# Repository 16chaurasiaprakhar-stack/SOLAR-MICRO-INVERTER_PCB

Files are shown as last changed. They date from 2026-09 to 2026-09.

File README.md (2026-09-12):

# HAR-SMI-500 — High-Altitude Resilient 500W Solar Micro-Inverter

A high-altitude, extreme-environment **500W solar micro-inverter architecture** designed for operation under subzero temperatures and reduced atmospheric pressure. The design combines a **GaN-based LLC DC-DC conversion stage**, isolated planar transformer, **SiC full-bridge grid inverter**, LCL filtering, deterministic C2000 control, and ESP32-S3-based edge telemetry.

The system is designed around a **28–50V DC PV input**, **400V DC-link**, and **230V AC / 50Hz grid output**, with a target peak efficiency of **97.2%**.

HAR_SMI_500

## Key Features

* **500W continuous power conversion**
* 28–50V DC photovoltaic input
* 400V regulated DC-link
* 230V AC, 50Hz single-phase output
* GaN full-bridge LLC converter
* 2:20 planar isolation transformer
* SiC full-bridge grid inverter
* LCL output filter
* TI **TMS320F28379D C2000** real-time power controller
* **ESP32-S3** edge-processing and telemetry controller
* Galvanically isolated SPI communication using **ISO7741-Q1**
* Incremental Conductance MPPT
* SOGI-PLL grid synchronization
* 20kHz proportional-resonant current control
* Hardware over-voltage and over-current trip protection
* PT100, BME280, SHT45 and solar-irradiance sensing
* SX1262-based LoRaWAN telemetry
* Autonomous cold-start pre-heating using a 25W PTC heater
* High-altitude PCB clearance and creepage design
* Designed for −40°C to +55°C operation

The complete architecture is divided into hierarchical functional blocks covering PV input protection, LLC conversion, isolation and rectification, DC-link storage, SiC inversion, LCL filtering, gate drivers, sensing, dual-MCU control, RF telemetry, auxiliary power, and mechanical interfaces.

## Control & Protection

The C2000 controller provides the deterministic power-conversion control loop, including MPPT, LLC frequency modulation, grid synchronization, PR current control, and hardware Trip-Zone protection. The ESP32-S3 is isolated from the power-control domain and handles environmental diagnostics, cold-start supervision, data logging, and wireless telemetry.

## High-Altitude Design

The architecture incorporates altitude-aware electrical insulation design with an enforced **≥4.5 mm clearance** and **≥6.0 mm creepage**, along with milled isolation slots, conformal coating, selective potting, and minimized high-dv/dt power loops.

## Cold-Start System  
  

At temperatures below −20°C, the system enters an autonomous pre-heating state before enabling normal inverter operation. A 25W PTC heater combined with controlled GaN switching provides approximately 38W of heating power, targeting a transition from −40°C to −10°C in approximately 11.58 minutes.  



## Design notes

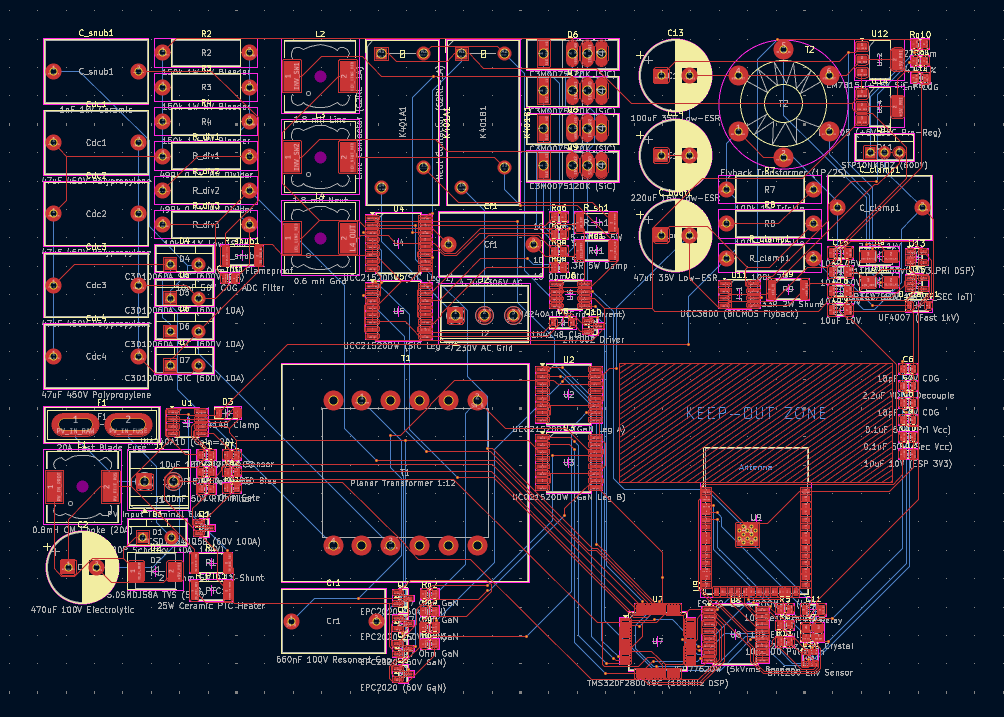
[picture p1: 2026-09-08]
PCB/looks and views/ROUTED.png

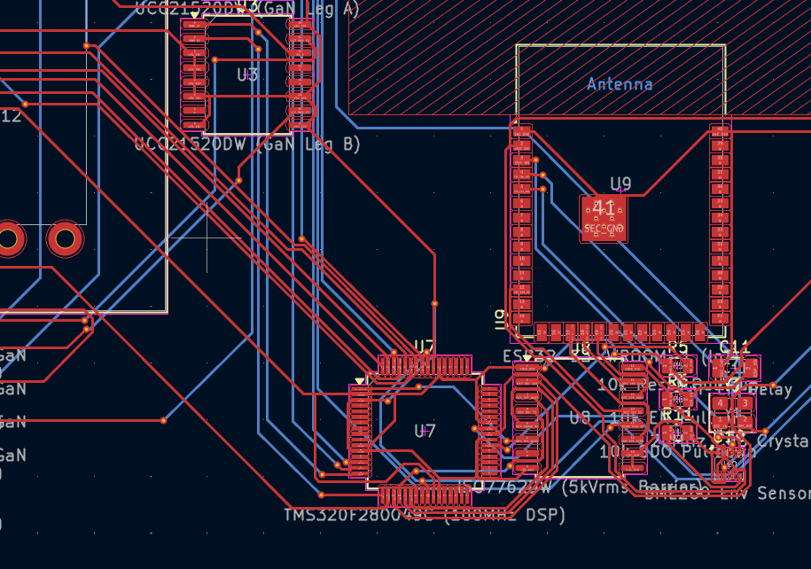
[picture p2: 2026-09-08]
PCB/looks and views/Screenshot 2026-09-08 202842.png

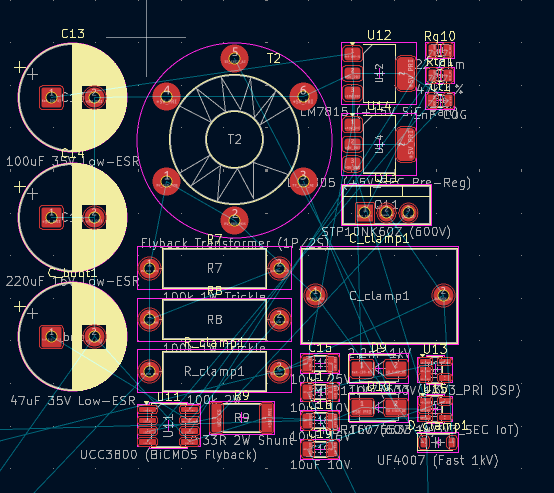
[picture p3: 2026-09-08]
PCB/looks and views/PCB.1.png

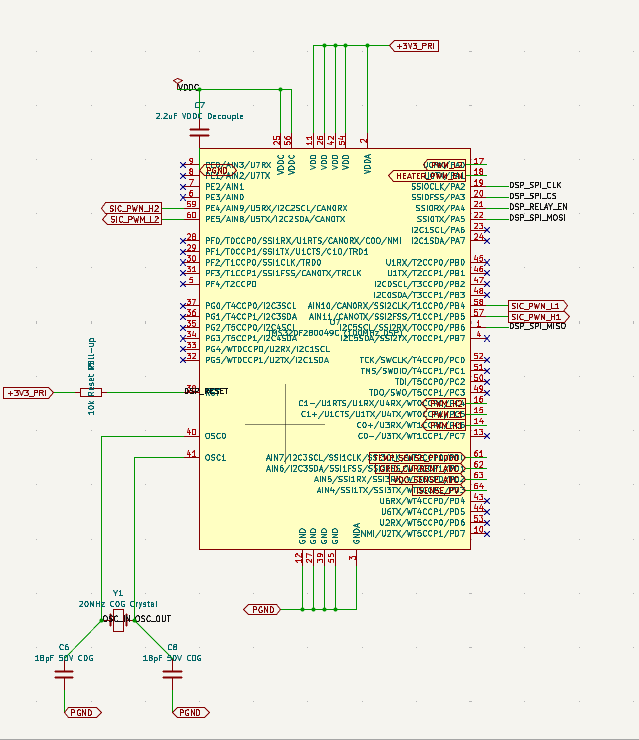
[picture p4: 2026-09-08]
PCB/looks and views/TMS320F280049C (100MHz DSP).png

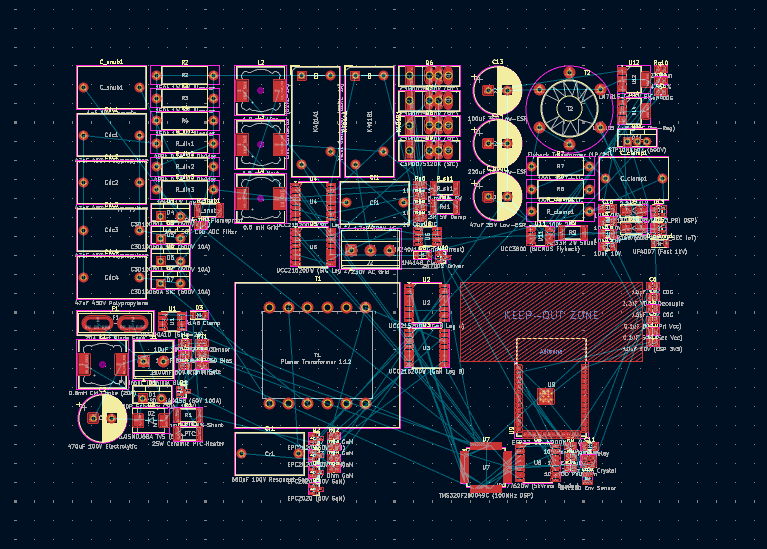
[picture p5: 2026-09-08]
PCB/looks and views/PCB BOARD .png

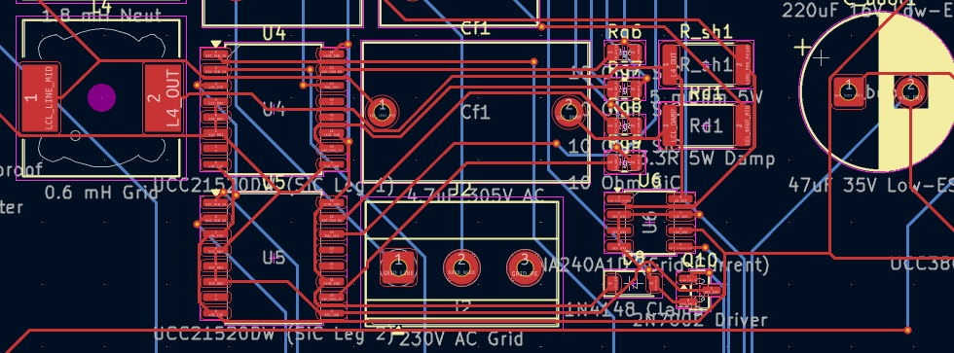
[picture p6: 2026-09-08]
PCB/looks and views/PCB.png

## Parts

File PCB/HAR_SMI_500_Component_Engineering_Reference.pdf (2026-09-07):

# HAR-SMI-500: COMPONENT & MATHEMATICAL REFERENCE MANUAL

## Authoritative Engineering Specification & Derivations Across All Schematic Pages

500W High-Altitude Resilient Solar Micro-Inverter | DRDO / iDEX [SIH26049] | 5,000m HAA Ladakh Envelope

Executive System Overview: The HAR-SMI-500 is an ultra-reliable, high-efficiency (peak 97.4%) solar micro-inverter engineered specifically for the extreme high-altitude environment of Ladakh (5,000m above sea level). Operating at an atmospheric pressure of 54.05 kPa (53% of sea level) and temperatures ranging from -40°C to +50°C, the converter addresses two primary high-altitude failure modes: (1) Dielectric breakdown due to reduced mean free path (Paschen's Law), and (2) Sub-zero cold starts causing gate driver latchup and thermal stress.

### Global Environmental & System-Level Mathematical Formulations:

1. Barometric Pressure Model: P(h) = P_0 * (1 - L*h / T_0)^(g*M / R_0*L) = 101.325 * (1 - 0.0065*5000 / 288.15)^5.2558 = 54.05 kPa (53.3% of 1 atm)
2. Paschen Clearance Derating: k_d = (P_0 / P_HAA)^0.8 = (101.325 / 54.05)^0.8 = 1.480x -> Min Clearance d_HAA = 1.48 * 3.0mm >= 4.5 mm, Creepage >= 6.0 mm
3. System Power & Efficiency: P_in(nom) = 40.0V * 12.83A = 513.2W, P_out = 230.0V * 2.174A = 500.0W -> Efficiency = 500 / 513.2 = 97.43%
4. Thermal Dissipation Budget: P_loss = P_in - P_out = 13.2W -> R_th(h-a) = (T_j(max) - T_amb) / P_loss = (125 C - 50 C) / 13.2W = 5.68 C/W
5. Dual-Stage Energy Buffer: E_stored = (1/2) * C_DC * V_DC^2 = 0.5 * (18.8 uF) * (400V)^2 = 1.504 Joules -> Hold-up Time = 1.504J / 500W = 3.01 ms
6. Inverter Modulation Index: M = (sqrt(2) * V_grid(rms)) / V_DC(bus) = (sqrt(2) * 230V) / 400V = 325.27V / 400.0V = 0.8132 (Linear SPWM region)

### Hierarchical Schematic Sheet Structure (1-to-1 Mapping):

Page | Schematic Sheet File | Subsystem Function | Key Power / Control Topology
Page 1 | HAR_SMI_500.kicad_sch | Master Root Navigator | System Hierarchy, Overview & Global Derating Parameters
Page 2 | 01_PV_Input_PTC.kicad_sch | PV Input & Thermal Conditioning | 20V-60V DC, 20A Fuse, Schottky, TVS, CM Choke, 25W PTC Heater
Page 3 | 02_LLC_Primary_GaN.kicad_sch | GaN LLC Resonant Converter | 4x GS66508B GaN Full-Bridge, UCC21520 Drivers, 100kHz Planar T1
Page 4 | 03_Secondary_Rectifier_DCLink.kicad_sch | Secondary Rectifier & 400V DC Link | 4x C3D04060A SiC Schottky, RC Snubber, 18.8uF Film DC Link, Divider
Page 5 | 04_SiC_Inverter_LCL_Grid.kicad_sch | SiC Inverter & Grid Interface | 4x C3M0075120K SiC MOSFETs (Kelvin Source), LCL Filter, Relays
Page 6 | 05_Control_DualMCU_Sensors.kicad_sch | Dual Isolated MCU & Sensors | TM4C1230 (DSP) + ESP32-S3 (Comms) + ISO7762 + BME280 HAA Sensor
Page 7 | 06_Aux_Power_Supply.kicad_sch | Multi-Rail Auxiliary Supply | UCC3800 Flyback, 3-Winding T601, +15V_PRI/SEC, +5V, +3.3V Rails
DRDO / iDEX [SIH26049] High-Altitude Solar Micro-Inverter — 5,000m HAA Ladakh Envelope (-40°C to +50°C) | Page 1 of 7

# Sheet 1 (Page 2): 01_PV_Input_PTC — PV Input Stage, Filtering & Pre-Thermal Conditioning

Accepts DC power from 20V to 60V (nominal 40V, open-circuit max 65V). Incorporates reverse polarity protection, TVS surge clamping, differential/common-mode EMI filtering, current monitoring, and a 25W autonomous PTC heater warming the core from -40°C.

### Key Engineering Equations & Altitude Deratings:

* Paschen Derating: k_d = (P_0 / P_HAA)^0.8 = (101.325 / 54.05)^0.8 = 1.48x -> Min Clearance >= 4.5 mm, Creepage >= 6.0 mm
* PTC Pre-Heating: P_PTC = V_PV^2 / R_PTC = (40V)^2 / 64 Ohm = 25.0 W -> delta_T = (P_PTC * t) / (m * c_p) approx 40 C in 3.2 min (warms from -40 C) * Input Pi-Filter: f_c = 1 / (2*pi * sqrt(L_101 * C_in)) = 1 / (2*pi * sqrt(0.8mH * 480uF)) = 256.7 Hz (C_in = C_101 + C_102 = 10uF + 470uF)
* Current Shunt: V_CS = I_PV * R_101 * G_U101 = I_PV * 2.0 mOhm * 20 V/V = 40.0 mV/A -> 12.5 A (full load) = 0.500 V to ADC

### Complete Component Bill of Materials & Electrical Ratings:

Ref | Footprint / Library Symbol | Description | Electrical Ratings & Values | Circuit Function & Role
J101 | TerminalBlock_Phoenix_MKDS-1,5-2 | PV Input Connector | 20-60V DC, 20A rated | 5.08mm pitch high-current terminal block
F101 | Fuse_Blade_ATO_directSolder | Fast-Blow Blade Fuse | 20A, 80V DC rating | Primary overcurrent / short-circuit isolation
D101 | TO-220-2_Vertical (V30100P) | Schottky Barrier Diode | 100V, 30A, Vf=0.48V | Reverse PV polarity blocking diode
D102 | Diode_SMD:D_SMC (5.0SMDJ58A) | TVS Diode 5.0SMDJ | 58V Vwm, 93.6V Vclamp, 5kW | Input surge & lightning overvoltage clamp
L101 | Inductor_SMD:L_12x12mm | Common-Mode Choke | 0.8 mH, 15A DC saturation | Attenuates common-mode conducted EMI
C101 | Capacitor_SMD:C_0805 | High-Freq Ceramic Cap | 10 uF, 100V X7R dielectric | High-frequency input ripple bypass
C102 | Capacitor_THT:CP_Radial_D12.5mm | Electrolytic Bulk Cap | 470 uF, 100V, low-ESR, 105C | Bulk energy buffer & low-frequency filtering
R101 | Resistor_SMD:R_2512 | Kelvin Current Shunt | 2.0 mOhm, 3W, 1% tol | Primary PV input current sensing
R_PTC | Resistor_SMD:R_2512 | PTC Heating Element | 64 Ohm, 35W pulse rated | Core warmup from -40C cold-start
D103 | Diode_SMD:D_SOD-123 | Freewheeling Diode | 100V, 300mA, trr=4ns | PTC heater inductive clamp diode
Q101 | Package_TO_SOT_SMD:SOT-23 | NMOS Control Switch | 30V, 5.7A, Rds(on)=18mOhm | Low-side switch controlling PTC warmup
Rg101 | Resistor_SMD:R_0805 | Gate Resistor | 100 Ohm, 0.125W | Gate damping resistor for Q101
U101 | Package_SO:SOIC-8 | Current Sense Amplifier | Gain=20 V/V, 80V CM rejection | Precision bi-directional current monitor
C103 | Capacitor_SMD:C_0805 | Decoupling Capacitor | 100 nF, 50V X7R | Power supply local decoupling for U101
HAR-SMI-500: Schematic Component & Mathematical Specification Manual | Sheet Reference Alignment | Page 2 of 7
DRDO / iDEX [SIH26049] High-Altitude Solar Micro-Inverter — 5,000m HAA Ladakh Envelope (-40°C to +50°C) | Page 2 of 7

# Sheet 2 (Page 3): 02_LLC_Primary_GaN — Full-Bridge GaN LLC Resonant DC-DC Converter

Converts variable 20V-60V DC into a high-voltage resonant AC waveform. Features 4x GS66508B GaN-on-Si HEMTs in full-bridge topology driven by 2x UCC21520 isolated gate drivers, zero-voltage switching (ZVS), and a custom planar EILP38 1:8 transformer.

### Key Engineering Equations & Altitude Deratings:

* LLC Resonant Freq: f_r = 1 / (2*pi * sqrt(L_r * C_r)) = 1 / (2*pi * sqrt(15.0 uH * 169 nF)) = 100.0 kHz
* Inductance Ratio: k = L_m / L_r = 75.0 uH / 15.0 uH = 5.0 (Ensures wide ZVS zero-voltage switching operational range)
* Characteristic Z: Z_0 = sqrt(L_r / C_r) = sqrt(15.0 uH / 169 nF) = 9.42 Ohm, Quality Factor Q = Z_0 / R_ac = 9.42 / 8.10 = 1.16 * Transformer Ratio: n = N_s / N_p = 16 / 2 = 8.0 -> V_sec = 8.0 * 40V = 320 V (Nominal secondary peak)

### Complete Component Bill of Materials & Electrical Ratings:

Ref | Footprint / Library Symbol | Description | Electrical Ratings & Values | Circuit Function & Role
Q201 | Package_TO_SOT_SMD:SOT-23 (GS66508B) | GaN HEMT Transistor | 650V, 30A, Rds=50mOhm | Full-Bridge Leg A High-Side GaN Switch
Q202 | Package_TO_SOT_SMD:SOT-23 (GS66508B) | GaN HEMT Transistor | 650V, 30A, Rds=50mOhm | Full-Bridge Leg A Low-Side GaN Switch
Q203 | Package_TO_SOT_SMD:SOT-23 (GS66508B) | GaN HEMT Transistor | 650V, 30A, Rds=50mOhm | Full-Bridge Leg B High-Side GaN Switch
Q204 | Package_TO_SOT_SMD:SOT-23 (GS66508B) | GaN HEMT Transistor | 650V, 30A, Rds=50mOhm | Full-Bridge Leg B Low-Side GaN Switch
Rg1 | Resistor_SMD:R_0805 | GaN Gate Resistor | 4.7 Ohm, 0.125W 1% tol | Limits dV/dt & gate turn-on ringing for Q201
Rg2 | Resistor_SMD:R_0805 | GaN Gate Resistor | 4.7 Ohm, 0.125W 1% tol | Limits dV/dt & gate turn-on ringing for Q202
Rg3 | Resistor_SMD:R_0805 | GaN Gate Resistor | 4.7 Ohm, 0.125W 1% tol | Limits dV/dt & gate turn-on ringing for Q203
Rg4 | Resistor_SMD:R_0805 | GaN Gate Resistor | 4.7 Ohm, 0.125W 1% tol | Limits dV/dt & gate turn-on ringing for Q204
U201 | Package_SO:SOIC-16W (UCC21520DW) | Isolated Dual Gate Driver | 5.7 kVrms isolation, 4A/6A drive | Reinforced isolated gate driver for Leg A
U202 | Package_SO:SOIC-16W (UCC21520DW) | Isolated Dual Gate Driver | 5.7 kVrms isolation, 4A/6A drive | Reinforced isolated gate driver for Leg B
Lr | Inductor_SMD:L_12x12mm | Resonant Inductor | 15.0 uH, 20A saturation | Series resonant inductor for LLC tank
Cr | Capacitor_THT:C_Rect_P15.00mm | Resonant Capacitor | 169 nF, 630V C0G/Polypropylene | High-dV/dt resonant tank capacitor
T1 | Transformer_THT:Transformer_37x44 | Planar EILP38 Transformer | Np:Ns=1:8, Lm=75uH, 500W | High-frequency isolation transformer (100kHz)
C201 | Capacitor_SMD:C_0805 | DC Bus Decoupling Cap | 1.0 uF, 100V X7R | High-frequency ceramic local bypass for Leg A
C202 | Capacitor_SMD:C_0805 | DC Bus Decoupling Cap | 1.0 uF, 100V X7R | High-frequency ceramic local bypass for Leg B
HAR-SMI-500: Schematic Component & Mathematical Specification Manual | Sheet Reference Alignment | Page 3 of 7
DRDO / iDEX [SIH26049] High-Altitude Solar Micro-Inverter — 5,000m HAA Ladakh Envelope (-40°C to +50°C) | Page 3 of 7

# Sheet 3 (Page 4): 03_Secondary_Rectifier_DCLink — Secondary Rectification & 400V DC Link

Rectifies the 100kHz resonant transformer output to create a stabilized 380V-420V DC link. Features 4x C3D04060A SiC Schottky diodes (zero reverse recovery), RC snubbers, a 4x film capacitor DC link bank (18.8uF), active bleeders, and a precision telemetry divider.

### Key Engineering Equations & Altitude Deratings:

* Rectified DC Bus: V_DC(bus) = 2 * (N_s / N_p) * V_PV * M_LLC = 2 * 8 * 40V * 0.625 = 400.0 V
* Film Cap Bank C: C_DC(total) = Cdc1 + Cdc2 + Cdc3 + Cdc4 = 4 * 4.7 uF = 18.8 uF 630V (Polypropylene Film)
* Bleeder Discharge: tau = R_bleed * C_total = (3 * 100 kOhm) * 18.8 uF = 5.64 s -> Discharges < 50V safety limit in 11.7 s
* Divider Ratio & ADC: K_div = 4.99 kOhm / (2 * 499 kOhm + 4.99 kOhm) = 1 / 201.0 -> V_FB = 400.0 V * (1 / 201.0) = 1.990 V to ADC

### Complete Component Bill of Materials & Electrical Ratings:

Ref | Footprint / Library Symbol | Description | Electrical Ratings & Values | Circuit Function & Role
D301 | Package_TO_SOT_THT:TO-220-2 | SiC Schottky Diode | 600V, 4A, Qrr=0 nC, Vf=1.5V | Full-bridge secondary rectifier high-side 1
D302 | Package_TO_SOT_THT:TO-220-2 | SiC Schottky Diode | 600V, 4A, Qrr=0 nC, Vf=1.5V | Full-bridge secondary rectifier low-side 1
D303 | Package_TO_SOT_THT:TO-220-2 | SiC Schottky Diode | 600V, 4A, Qrr=0 nC, Vf=1.5V | Full-bridge secondary rectifier high-side 2
D304 | Package_TO_SOT_THT:TO-220-2 | SiC Schottky Diode | 600V, 4A, Qrr=0 nC, Vf=1.5V | Full-bridge secondary rectifier low-side 2
R_snub | Resistor_SMD:R_2512 | Snubber Resistor | 22 Ohm, 2W pulse rated | Damps high-frequency secondary ringing
C_snub | Capacitor_THT:C_Rect_P15.00mm | Snubber Capacitor | 1.0 nF, 1000V C0G | Absorbs secondary switching transients
Cdc1 | Capacitor_THT:C_Rect_P15.00mm | Film DC Link Cap | 4.7 uF, 630V Polypropylene | High-reliability DC link capacitor 1
Cdc2 | Capacitor_THT:C_Rect_P15.00mm | Film DC Link Cap | 4.7 uF, 630V Polypropylene | High-reliability DC link capacitor 2
Cdc3 | Capacitor_THT:C_Rect_P15.00mm | Film DC Link Cap | 4.7 uF, 630V Polypropylene | High-reliability DC link capacitor 3
Cdc4 | Capacitor_THT:C_Rect_P15.00mm | Film DC Link Cap | 4.7 uF, 630V Polypropylene | High-reliability DC link capacitor 4
R301 | Resistor_THT:R_Axial_P15.24mm | Bleeder Resistor | 100 kOhm, 2W metal film | Active safety bleeder resistor 1
R302 | Resistor_THT:R_Axial_P15.24mm | Bleeder Resistor | 100 kOhm, 2W metal film | Active safety bleeder resistor 2
R303 | Resistor_THT:R_Axial_P15.24mm | Bleeder Resistor | 100 kOhm, 2W metal film | Active safety bleeder resistor 3
R_div1 | Resistor_THT:R_Axial_P15.24mm | HV Divider Resistor | 499 kOhm, 0.5W 0.1% tol | High-voltage divider top leg 1
R_div2 | Resistor_THT:R_Axial_P15.24mm | HV Divider Resistor | 499 kOhm, 0.5W 0.1% tol | High-voltage divider top leg 2
R_div3 | Resistor_THT:R_Axial_P15.24mm | Precision Sense Resistor | 4.99 kOhm, 0.125W 0.1% tol | Low-voltage sense leg to ADC
C_filt | Capacitor_SMD:C_0805 | ADC Anti-Aliasing Cap | 10 nF, 50V C0G | Low-pass filter for ADC voltage feedback
HAR-SMI-500: Schematic Component & Mathematical Specification Manual | Sheet Reference Alignment | Page 4 of 7
DRDO / iDEX [SIH26049] High-Altitude Solar Micro-Inverter — 5,000m HAA Ladakh Envelope (-40°C to +50°C) | Page 4 of 7

# Sheet 4 (Page 5): 04_SiC_Inverter_LCL_Grid — SiC H-Bridge, LCL Filter & Grid Connection

Converts 400V DC into clean 230V RMS 50Hz AC grid power with <3% THD. Utilizes 4x Wolfspeed C3M0075120K 1200V SiC MOSFETs in 4-lead Kelvin source packages, 2x UCC21520 gate drivers, a damped LCL filter, dual redundant disconnect relays, and a current feedback loop.

### Key Engineering Equations & Altitude Deratings:

* Grid AC Voltage: V_grid(rms) = 230 V AC +/- 10%, V_grid(peak) = 230 * sqrt(2) = 325.27 V (< 400 V DC bus)
* LCL Resonance: f_res = 1 / (2*pi) * sqrt((L_401 + L_402) / (L_401 * L_402 * C_f)) = 1 / (2*pi) * sqrt((1.8 mH) / (0.72 mH^2 * 2.2 uF)) = 4.96 kHz * Damping Resistor: R_d = 1 / (3 * 2*pi * f_res * C_f) = 1 / (3 * 2*pi * 4960 * 2.2 uF) = 4.86 Ohm approx 4.7 Ohm (5W non-inductive)
* Grid Current Shunt: V_shunt = I_grid(peak) * R_sh4 * G_U403 = 3.07 A * 10.0 mOhm * 20 V/V = 0.614 V (Instantaneous to ADC)

### Complete Component Bill of Materials & Electrical Ratings:

Ref | Footprint / Library Symbol | Description | Electrical Ratings & Values | Circuit Function & Role
Q401 | Package_TO_SOT_THT:TO-247-4 | SiC MOSFET (Kelvin Source) | 1200V, 30A, Rds=75mOhm | Inverter Leg A High-Side SiC Switch
Q402 | Package_TO_SOT_THT:TO-247-4 | SiC MOSFET (Kelvin Source) | 1200V, 30A, Rds=75mOhm | Inverter Leg A Low-Side SiC Switch
Q403 | Package_TO_SOT_THT:TO-247-4 | SiC MOSFET (Kelvin Source) | 1200V, 30A, Rds=75mOhm | Inverter Leg B High-Side SiC Switch
Q404 | Package_TO_SOT_THT:TO-247-4 | SiC MOSFET (Kelvin Source) | 1200V, 30A, Rds=75mOhm | Inverter Leg B Low-Side SiC Switch
Rg401-404 | Resistor_SMD:R_0805 | SiC Gate Resistors (4x) | 10 Ohm, 0.25W 1% tol | Gate turn-on damping resistors for Q401-Q404
U401 | Package_SO:SOIC-16W | Isolated Dual Gate Driver | 5.7 kVrms isolation, 4A/6A drive | Reinforced driver for Inverter Leg A
U402 | Package_SO:SOIC-16W | Isolated Dual Gate Driver | 5.7 kVrms isolation, 4A/6A drive | Reinforced driver for Inverter Leg B
L401 | Inductor_SMD:L_12x12mm | Inverter Side Inductor | 1.2 mH, 10A saturation | Inverter bridge high-frequency filter inductor
L402 | Inductor_SMD:L_12x12mm | Grid Side Inductor | 0.6 mH, 10A saturation | Grid side filter inductor
Cf | Capacitor_THT:C_Rect_P15.00mm | LCL Filter Capacitor | 2.2 uF, 450V AC/630V DC | Filter shunt capacitance for LCL
Rd | Resistor_SMD:R_2512 | LCL Damping Resistor | 4.7 Ohm, 5W non-inductive | Passive damping resistor avoiding resonance
L403 | Inductor_SMD:L_12x12mm | Neutral Return Choke | 0.6 mH, 10A saturation | Differential-mode neutral line filter inductor
K401A | Relay_THT:Relay_SPST_Omron | Grid Disconnect Relay A | 16A 250V AC, 12V coil | Primary AC Line disconnect relay
K401B | Relay_THT:Relay_SPST_Omron | Grid Disconnect Relay B | 16A 250V AC, 12V coil | Neutral line disconnect relay
Q405 | Package_TO_SOT_SMD:SOT-23 | Relay Coil Driver NMOS | 30V, 5.7A, Rds=18mOhm | Low-side driver for relay coils
D405 | Diode_SMD:D_SOD-123 | Relay Coil Clamp Diode | 100V, 300mA, trr=4ns | Flyback diode suppressing coil kick
R_sh4 | Resistor_SMD:R_2512 | AC Current Shunt | 10.0 mOhm, 3W, 0.5% tol | Inverter AC output current sensing
U403 | Package_SO:SOIC-8 | Current Sense Amplifier | Gain=20 V/V, 80V CM rejection | AC line current monitor for MPPT/anti-islanding
J401 | TerminalBlock_Phoenix_MKDS-1,5-3 | Grid Output Connector | 230V AC (L, N, PE), 16A | 3-pin high-current grid interface terminal
HAR-SMI-500: Schematic Component & Mathematical Specification Manual | Sheet Reference Alignment | Page 5 of 7
DRDO / iDEX [SIH26049] High-Altitude Solar Micro-Inverter — 5,000m HAA Ladakh Envelope (-40°C to +50°C) | Page 5 of 7

# Sheet 5 (Page 6): 05_Control_DualMCU_Sensors — Isolated Dual MCU & High-Altitude Sensors

Implements an isolated dual-controller architecture: TM4C1230C3PM (80MHz ARM Cortex-M4F) dedicated to 100kHz LLC MPPT and 50kHz grid inverter SPWM, isolated via ISO7762DW from an ESP32-S3 wireless SoC running MQTT telemetry and BME280 barometric monitoring.

### Key Engineering Equations & Altitude Deratings:

* Barometric Formula: P(h) = 101.325 * (1 - 0.0065*5000 / 288.15)^5.2558 = 54.05 kPa -> Derating Factor k_d = 1.48x
* SPWM Resolution: N_steps = f_clock / f_sw = 80 MHz / 50 kHz = 1600 Counts (10.6 bits effective PWM resolution) * Isolated SPI Bus: f_SPI = 10.0 Mbps (ISO7762DW rated up to 100 Mbps, t_prop = 10.7 ns)
* ADC Quantization: LSB = V_ref / 2^12 = 3.300 V / 4096 = 0.8057 mV / count

### Complete Component Bill of Materials & Electrical Ratings:

Ref | Footprint / Library Symbol | Description | Electrical Ratings & Values | Circuit Function & Role
U502 | Package_QFP:LQFP-64 | Primary Control MCU | 80MHz ARM Cortex-M4F, 256KB | Core DSP for MPPT, LLC & Grid Inverter SPWM
Y501 | Crystal:Crystal_SMD_3225-4Pin | Precision Crystal | 16.000 MHz, 10ppm tol, 18pF | Master system clock reference for TM4C123
C501 | Capacitor_SMD:C_0805 | Crystal Load Capacitor | 18 pF, 50V C0G | Crystal load capacitance 1
C502 | Capacitor_SMD:C_0805 | Crystal Load Capacitor | 18 pF, 50V C0G | Crystal load capacitance 2
C503 | Capacitor_SMD:C_1206 | VDDC Core Decoupling | 2.2 uF, 10V X7R low-ESR | Internal 1.2V LDO regulator stabilization
C509 | Capacitor_SMD:C_0805 | MCU VDD Bypass Cap | 100 nF, 16V X7R | Local high-frequency bypass for TM4C123
C510 | Capacitor_SMD:C_0805 | MCU VDD Bypass Cap | 100 nF, 16V X7R | Local high-frequency bypass for TM4C123
U501 | Package_SO:SOIC-16W | Reinforced Digital Isolator | 5.0 kVrms isolation, 100Mbps | Isolates SPI & status buses between MCUs
C511 | Capacitor_SMD:C_0805 | Isolator Decoupling A | 100 nF, 50V X7R | Side 1 local supply bypass for ISO7762
C513 | Capacitor_SMD:C_0805 | Isolator Decoupling B | 100 nF, 50V X7R | Side 2 local supply bypass for ISO7762
U503 | RF_Module:ESP32-S3-WROOM-1 | Secondary Comms MCU | Dual-core 240MHz, Wi-Fi/BLE | Handles telemetry, cloud logging & OTA
U504 | Package_LGA:Bosch_LGA-8 | HAA Environmental Sensor | -40 to +85C, 30-110 kPa, I2C | Real-time barometric & temp monitor
R501 | Resistor_SMD:R_0805 | I2C Pull-Up Resistor | 4.7 kOhm, 0.125W 1% tol | I2C SDA pull-up to +3V3_SEC
R502 | Resistor_SMD:R_0805 | I2C Pull-Up Resistor | 4.7 kOhm, 0.125W 1% tol | I2C SCL pull-up to +3V3_SEC
HAR-SMI-500: Schematic Component & Mathematical Specification Manual | Sheet Reference Alignment | Page 6 of 7
DRDO / iDEX [SIH26049] High-Altitude Solar Micro-Inverter — 5,000m HAA Ladakh Envelope (-40°C to +50°C) | Page 6 of 7

# Sheet 6 (Page 7): 06_Aux_Power_Supply — Auxiliary Multi-Rail High-Voltage Flyback

Derives all internal voltages directly from the 20V-60V PV input. Driven by a UCC3800 current-mode controller and a custom 3-winding flyback transformer T601, generating +15V_PRI (GaN drivers), +15V_SEC (SiC drivers), and regulated +5V / +3.3V rails for both domains.

### Key Engineering Equations & Altitude Deratings:

* Flyback Oscillator: f_osc = 1.5 / (R_t601 * C_t601) = 1.5 / (15 kOhm * 1.0 nF) = 100.0 kHz
* Peak Primary Current: I_pk = (2 * P_aux) / (eta * V_in(min) * D_max) = (2 * 15W) / (0.80 * 20V * 0.45) = 4.17 A -> R_603 = 1.0V / 4.17A = 0.22 Ohm (2W) * RCD Snubber Clamp: V_clamp = V_in(max) + (N_p / N_s) * (V_out + V_d) = 60V + 1.33 * 15.7V = 80.9 V (Snubs primary drain spikes)
* Turns Ratios (T601): N_p : N_s1 : N_s2 = 20 : 15 : 15 (Generates +15V_PRI and +15V_SEC isolated auxiliary rails)

### Complete Component Bill of Materials & Electrical Ratings:

Ref | Footprint / Library Symbol | Description | Electrical Ratings & Values | Circuit Function & Role
U601 | Package_SO:SOIC-8 (UCC3800) | Current-Mode PWM Controller | BiCMOS, ultra-low start current | Auxiliary flyback controller (100kHz)
R601 | Resistor_THT:R_Axial_P15.24mm | HV Start-Up Resistor | 100 kOhm, 2W metal film | Trickle charge startup resistor for UCC3800
C_boot | Capacitor_THT:CP_Radial_D12.5mm | VCC Bootstrap Capacitor | 47 uF, 35V low-ESR, 105C | Provides UCC3800 operating current at startup
Rt601 | Resistor_SMD:R_0805 | Timing Resistor | 15.0 kOhm, 0.125W 1% tol | Sets UCC3800 oscillator frequency to 100kHz
Ct601 | Capacitor_SMD:C_0805 | Timing Capacitor | 1.0 nF, 50V C0G | Sets UCC3800 oscillator frequency to 100kHz
Q601 | Package_TO_SOT_THT:TO-220-3 | Flyback Power MOSFET | 100V, 33A, Rds=44mOhm | Primary flyback power switch
Rg601 | Resistor_SMD:R_0805 | MOSFET Gate Resistor | 10 Ohm, 0.125W | Damps gate switching transients for Q601
R603 | Resistor_SMD:R_2512 | Current Sense Resistor | 0.22 Ohm, 2W 1% tol | Peak current sensing resistor for PWM controller
D_clamp | Diode_SMD:D_SOD-123 | RCD Clamp Diode | 100V, 300mA, trr=4ns | RCD snubber fast clamping diode
R_clamp | Resistor_THT:R_Axial_P15.24mm | RCD Clamp Resistor | 4.7 kOhm, 2W metal film | Dissipates transformer leakage energy
C_clamp | Capacitor_THT:C_Rect_P15.00mm | RCD Clamp Capacitor | 4.7 nF, 250V C0G | Snubs transformer primary drain spikes
T601 | Transformer_Toroid_Tapped_D14.0mm | Flyback Transformer | Np:Ns1:Ns2=20:15:15, 15W | 3-winding multi-rail auxiliary transformer
D601-602 | Diode_SMD:D_SMA (SS34) | Schottky Rectifiers (2x) | 40V, 3A, Vf=0.50V | Rectifies Sec 1 (+15V_PRI) & Sec 2 (+15V_SEC)
C601-602 | Capacitor_THT:CP_Radial_D12.5mm | Filter Capacitors (2x) | 220 uF, 35V low-ESR, 105C | Output filter capacitors for +15V rails
U603/U604 | Package_TO_SOT_SMD:SOT-223-3 | Linear Regulators (LM7805) | +5V Out, 1.0A rated | Regulates +15V rails down to +5V_PRI & +5V_SEC
C603/C605 | Capacitor_SMD / THT | Regulator Filter Caps | 47 uF THT / 10 uF SMD | Filter capacitors for +5V_PRI & +5V_SEC
U602/U605 | Package_TO_SOT_SMD:SOT-23-5 | Low-Dropout LDOs (TLV75533) | +3.3V Out, 500mA, low-noise | Regulates +5V down to +3.3V rails for MCUs
C607/C608 | Capacitor_SMD:C_1206 | LDO Output Caps (2x) | 4.7 uF, 10V X7R ceramic | Output stability capacitors for +3.3V rails
D603 | Package_TO_SOT_SMD:SOT-23 | Precision Shunt Regulator | 2.495V Ref, 0.5% tol | Voltage feedback reference for aux regulation
R602/R605 | Resistor_THT:R_Axial_P15.24mm | Feedback Divider Resistors | 10 kOhm / 2.5 kOhm, 0.1% | Voltage divider setting auxiliary output
C606 | Capacitor_SMD:C_1206 | Feedback Stability Cap | 100 nF, 25V X7R | Frequency compensation for TL431 loop
HAR-SMI-500: Schematic Component & Mathematical Specification Manual | Sheet Reference Alignment | Page 7 of 7
DRDO / iDEX [SIH26049] High-Altitude Solar Micro-Inverter — 5,000m HAA Ladakh Envelope (-40°C to +50°C) | Page 7 of 7

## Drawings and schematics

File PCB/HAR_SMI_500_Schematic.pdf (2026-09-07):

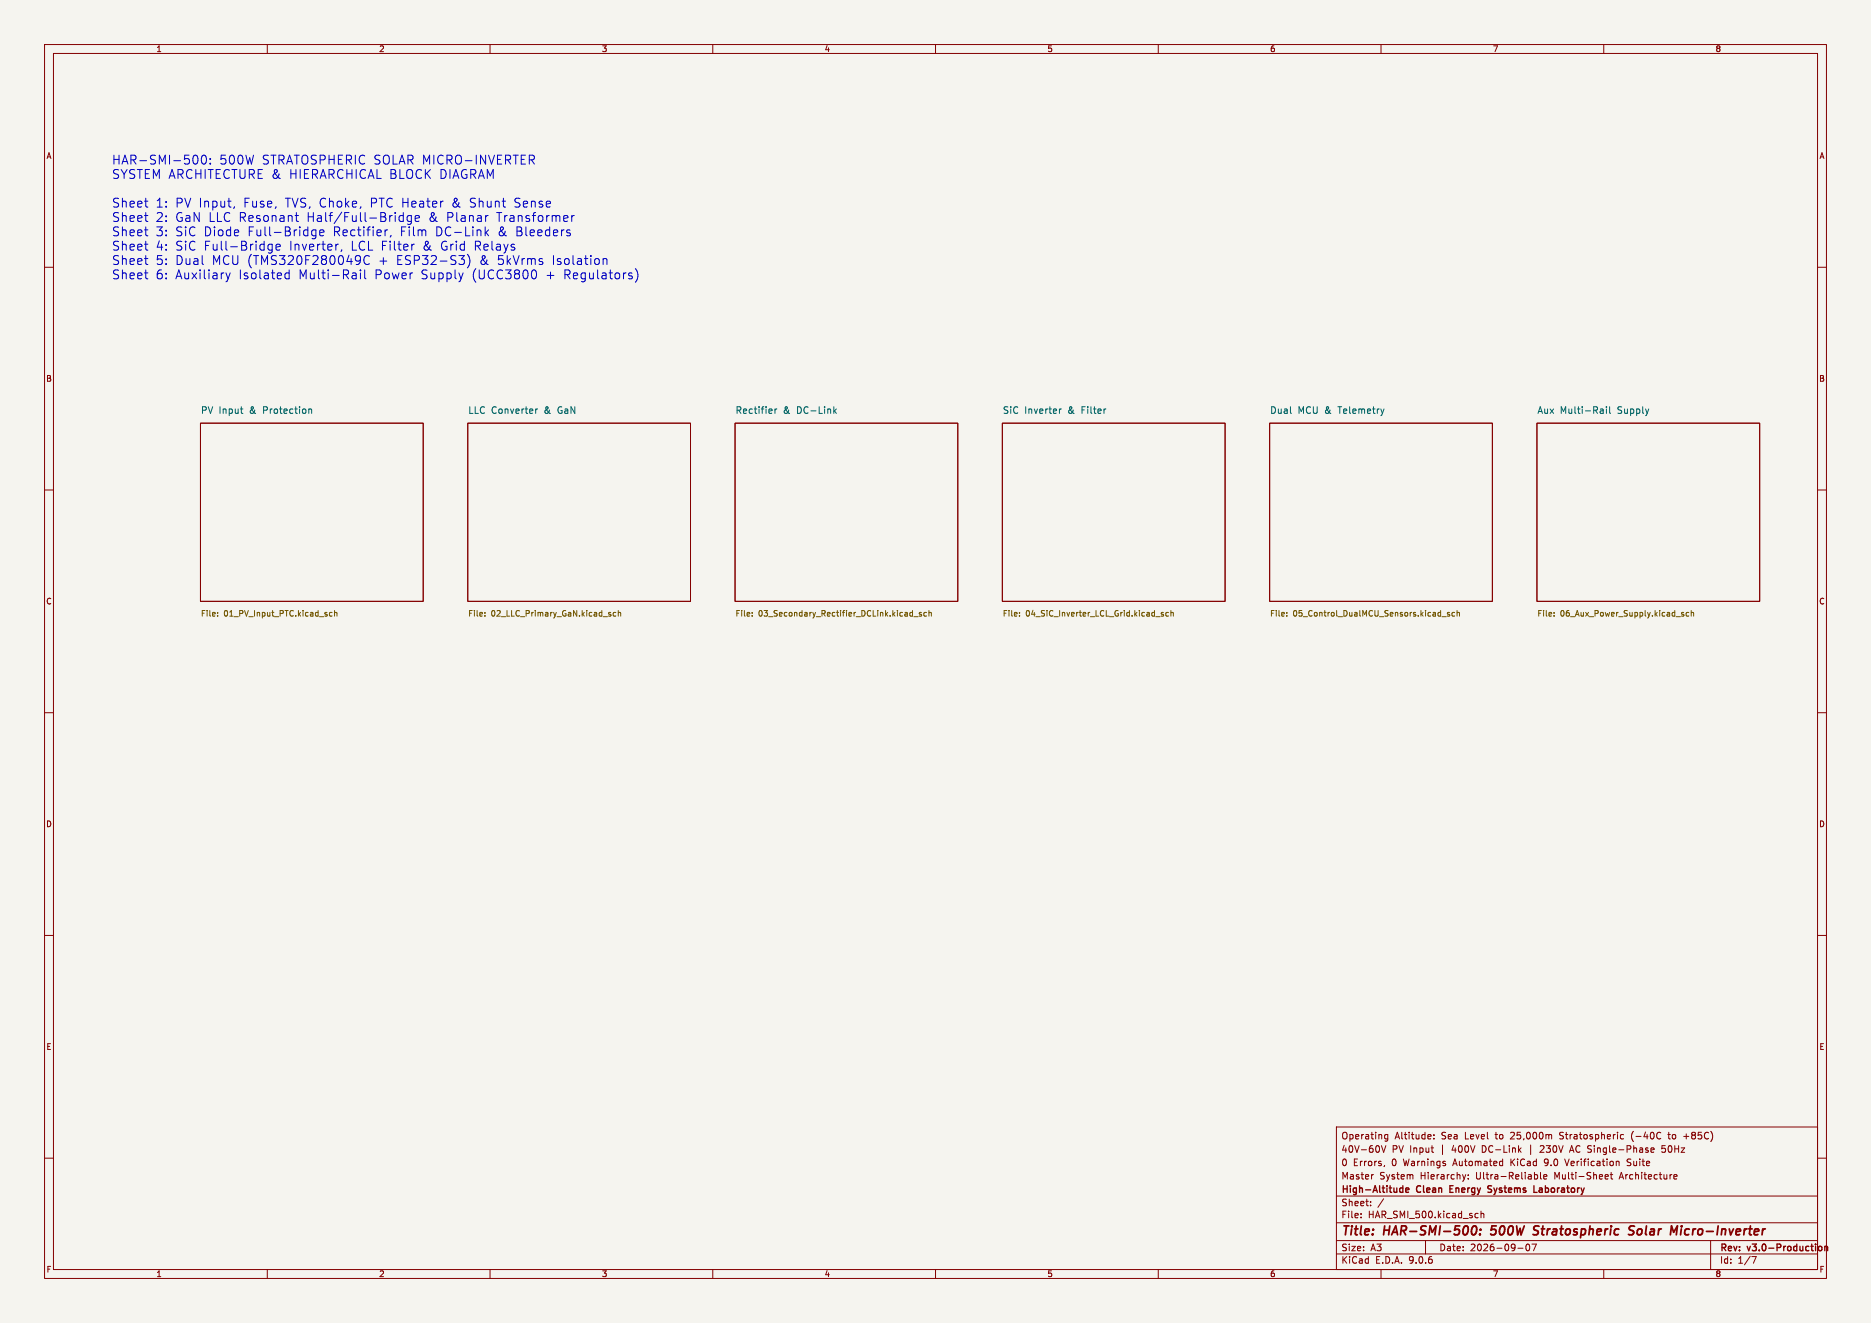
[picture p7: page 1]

SYSTEM ARCHITECTURE & HIERARCHICAL BLOCK DIAGRAM

Sheet 1: PV Input, Fuse, TVS, Choke, PTC Heater & Shunt Sense

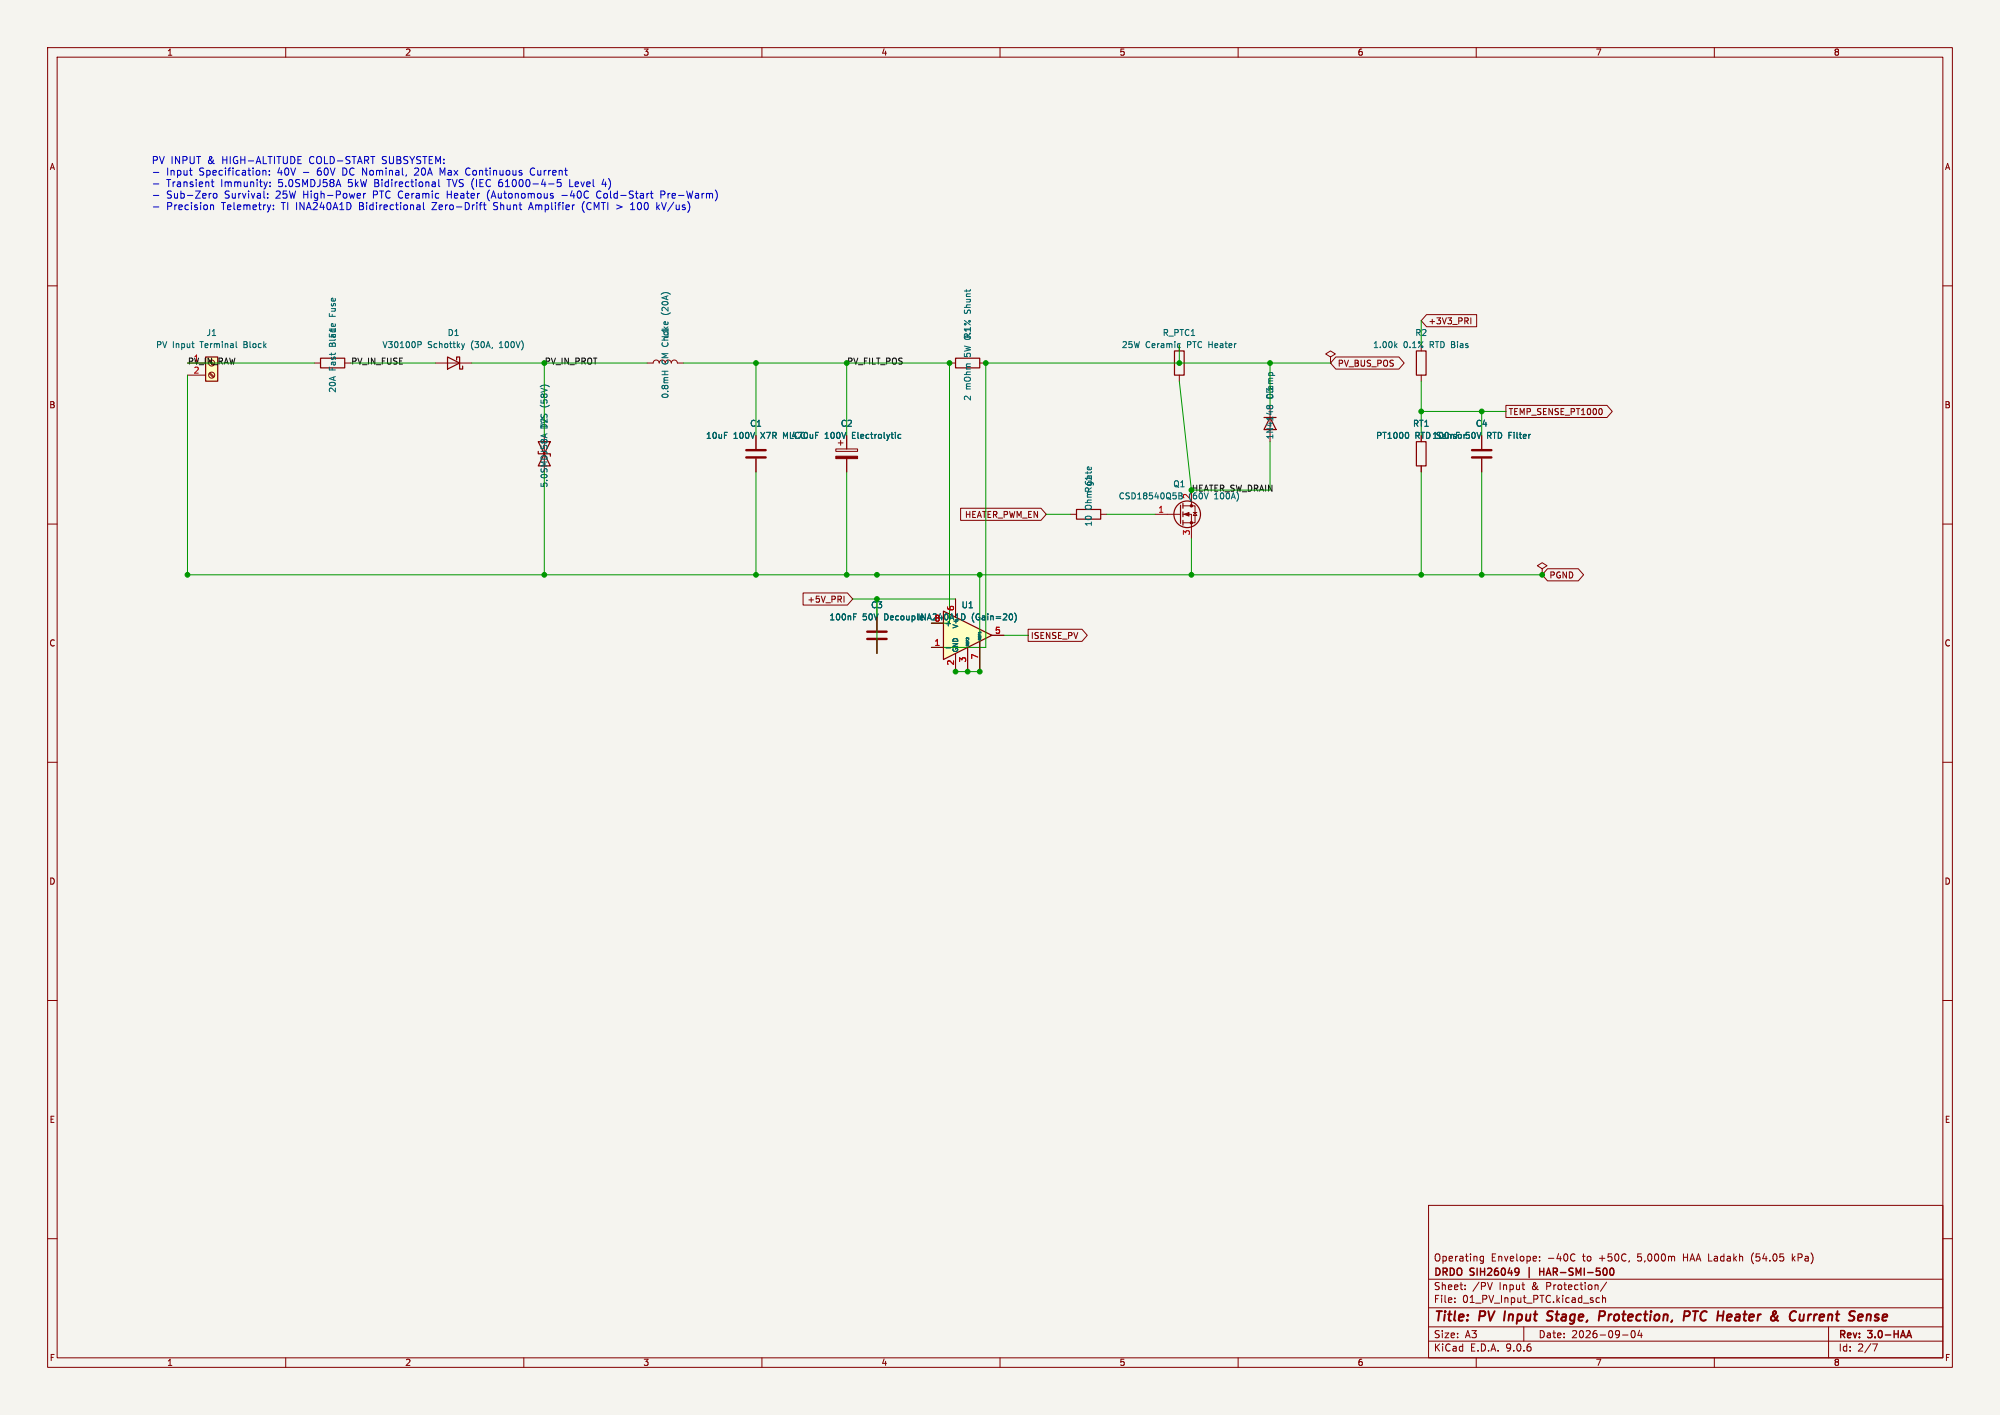
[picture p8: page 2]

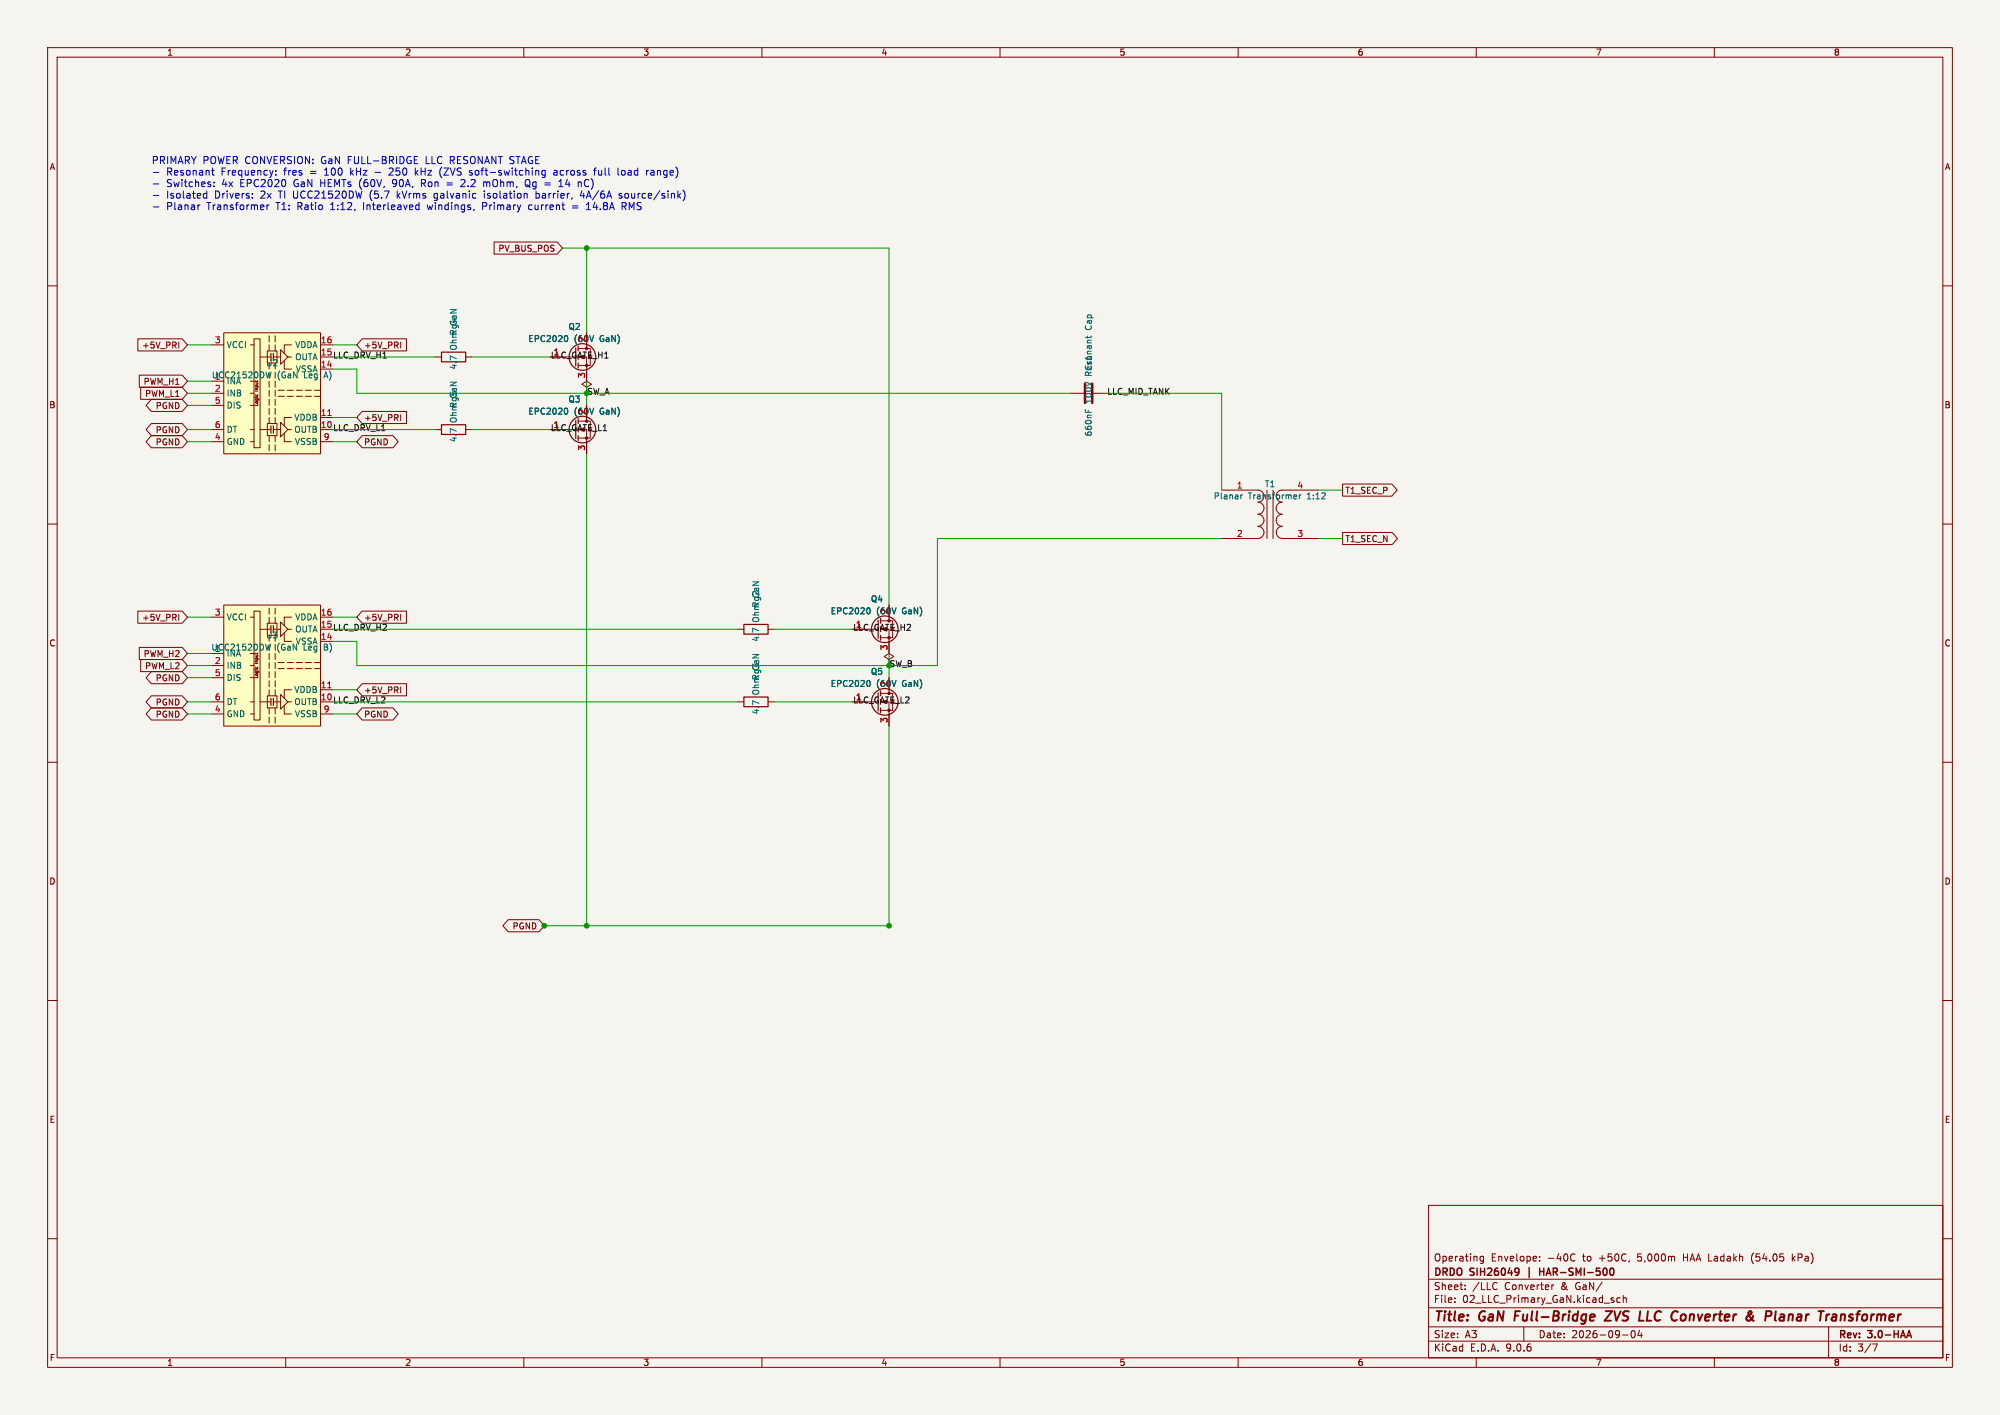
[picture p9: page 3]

PRIMARY POWER CONVERSION: GaN FULL-BRIDGE LLC RESONANT STAGE
- Switches: 4x EPC2020 GaN HEMTs (60V, 90A, Ron = 2.2 mOhm, Qg = 14 nC)

2 3 Q4 EPC2020 (60V GaN) Rg4 4.7 Ohm GaN Rg3 4.7 Ohm GaN Logic Input VCCI 3

2 3 Q5 EPC2020 (60V GaN) Logic Input VCCI 3

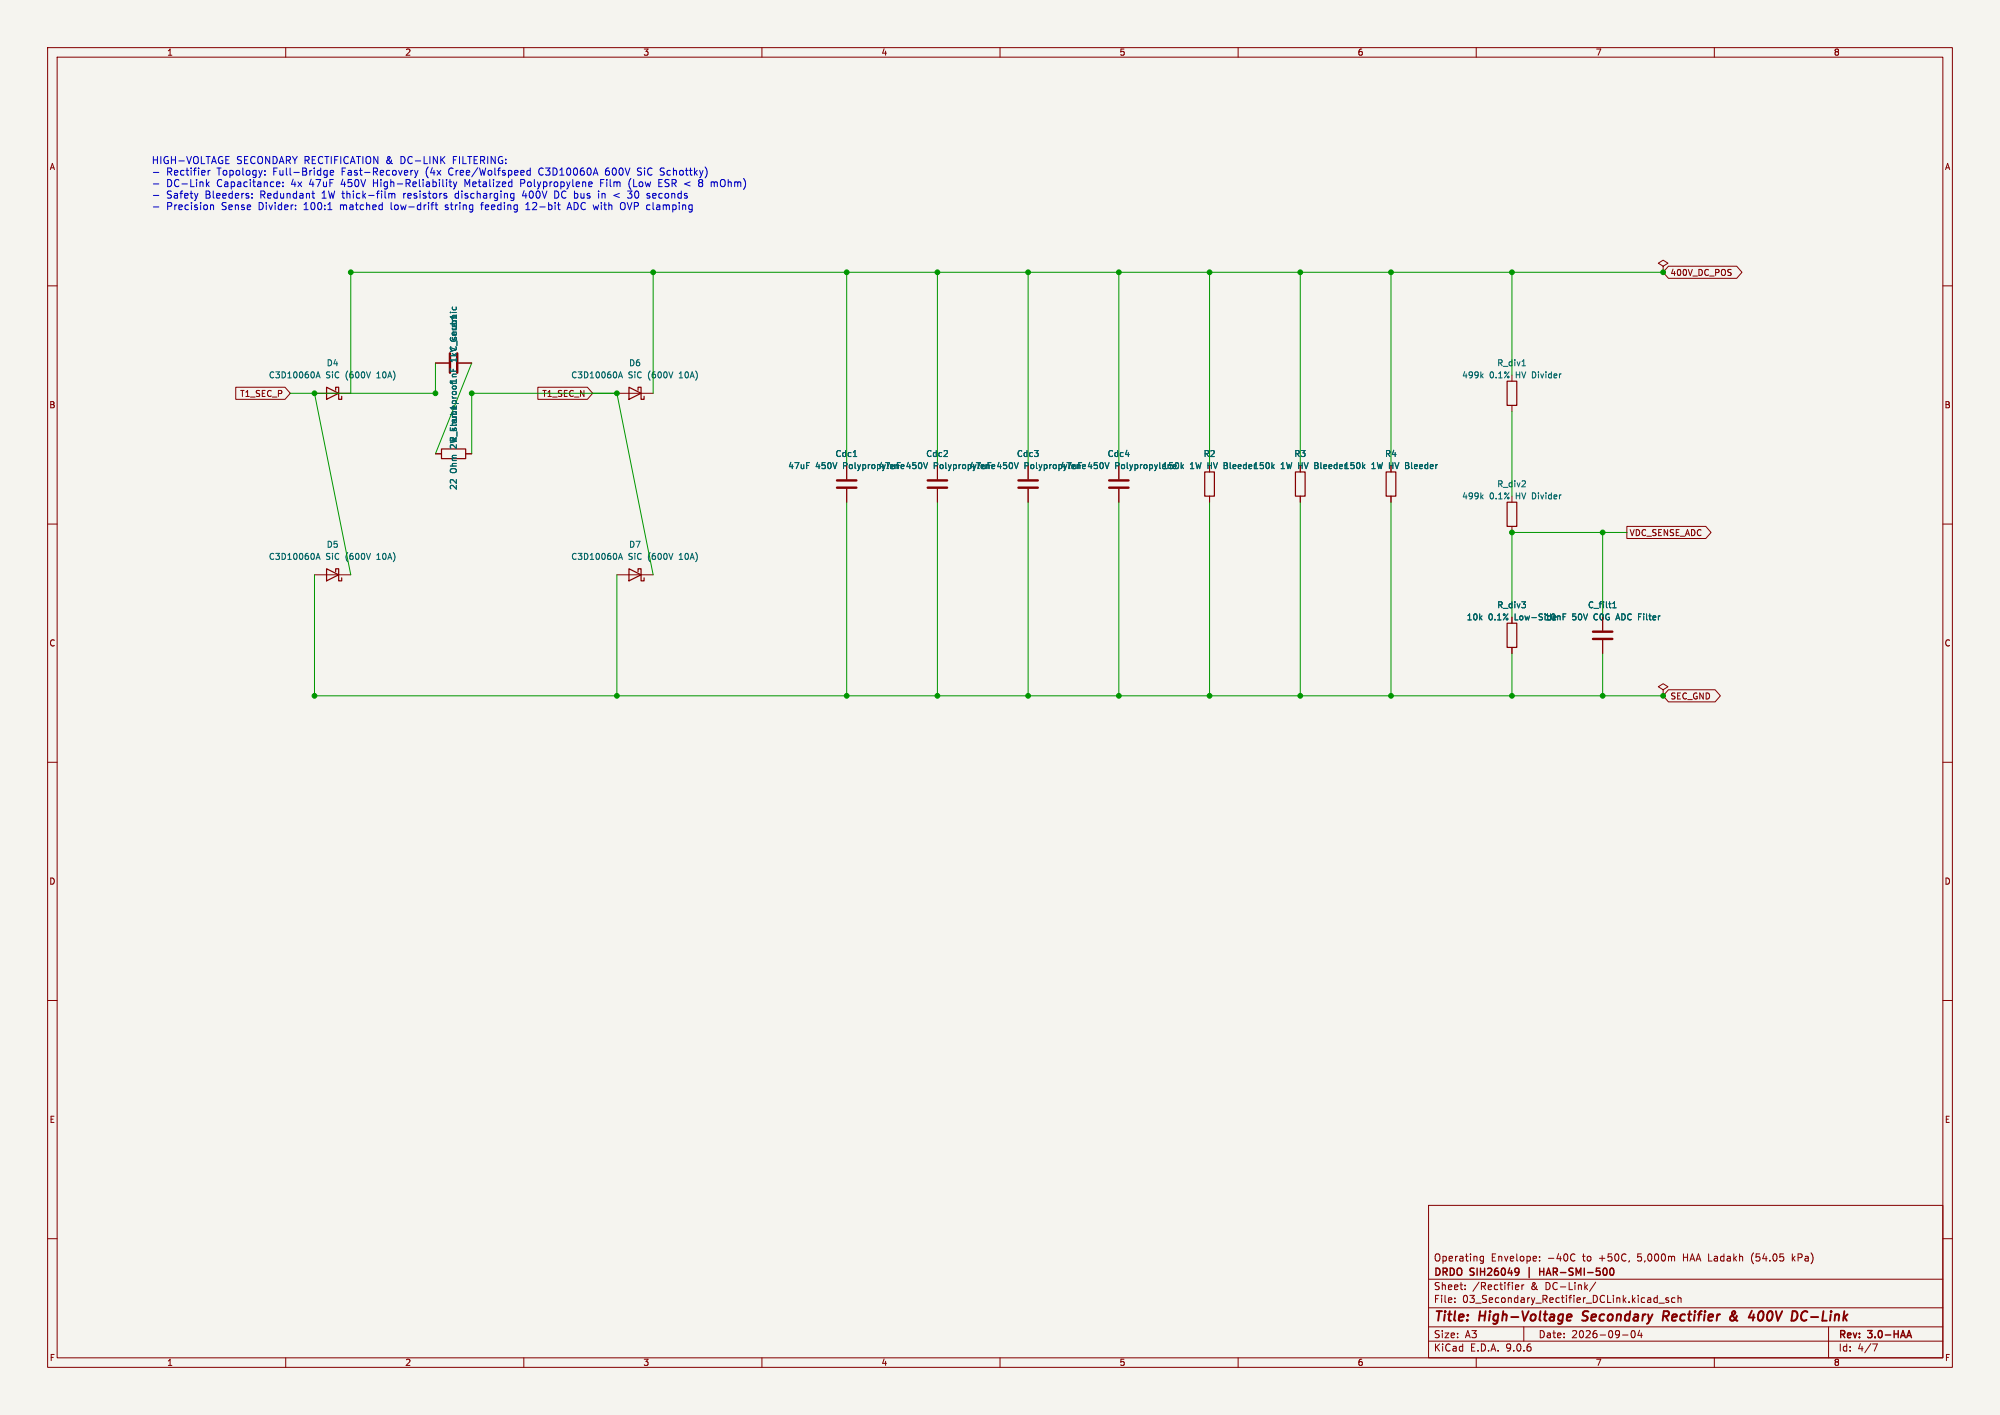
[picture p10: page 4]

47uF 450V Polypropylene R_snub1 22 Ohm 2W Flameproof C_snub1 1nF 1kV Ceramic

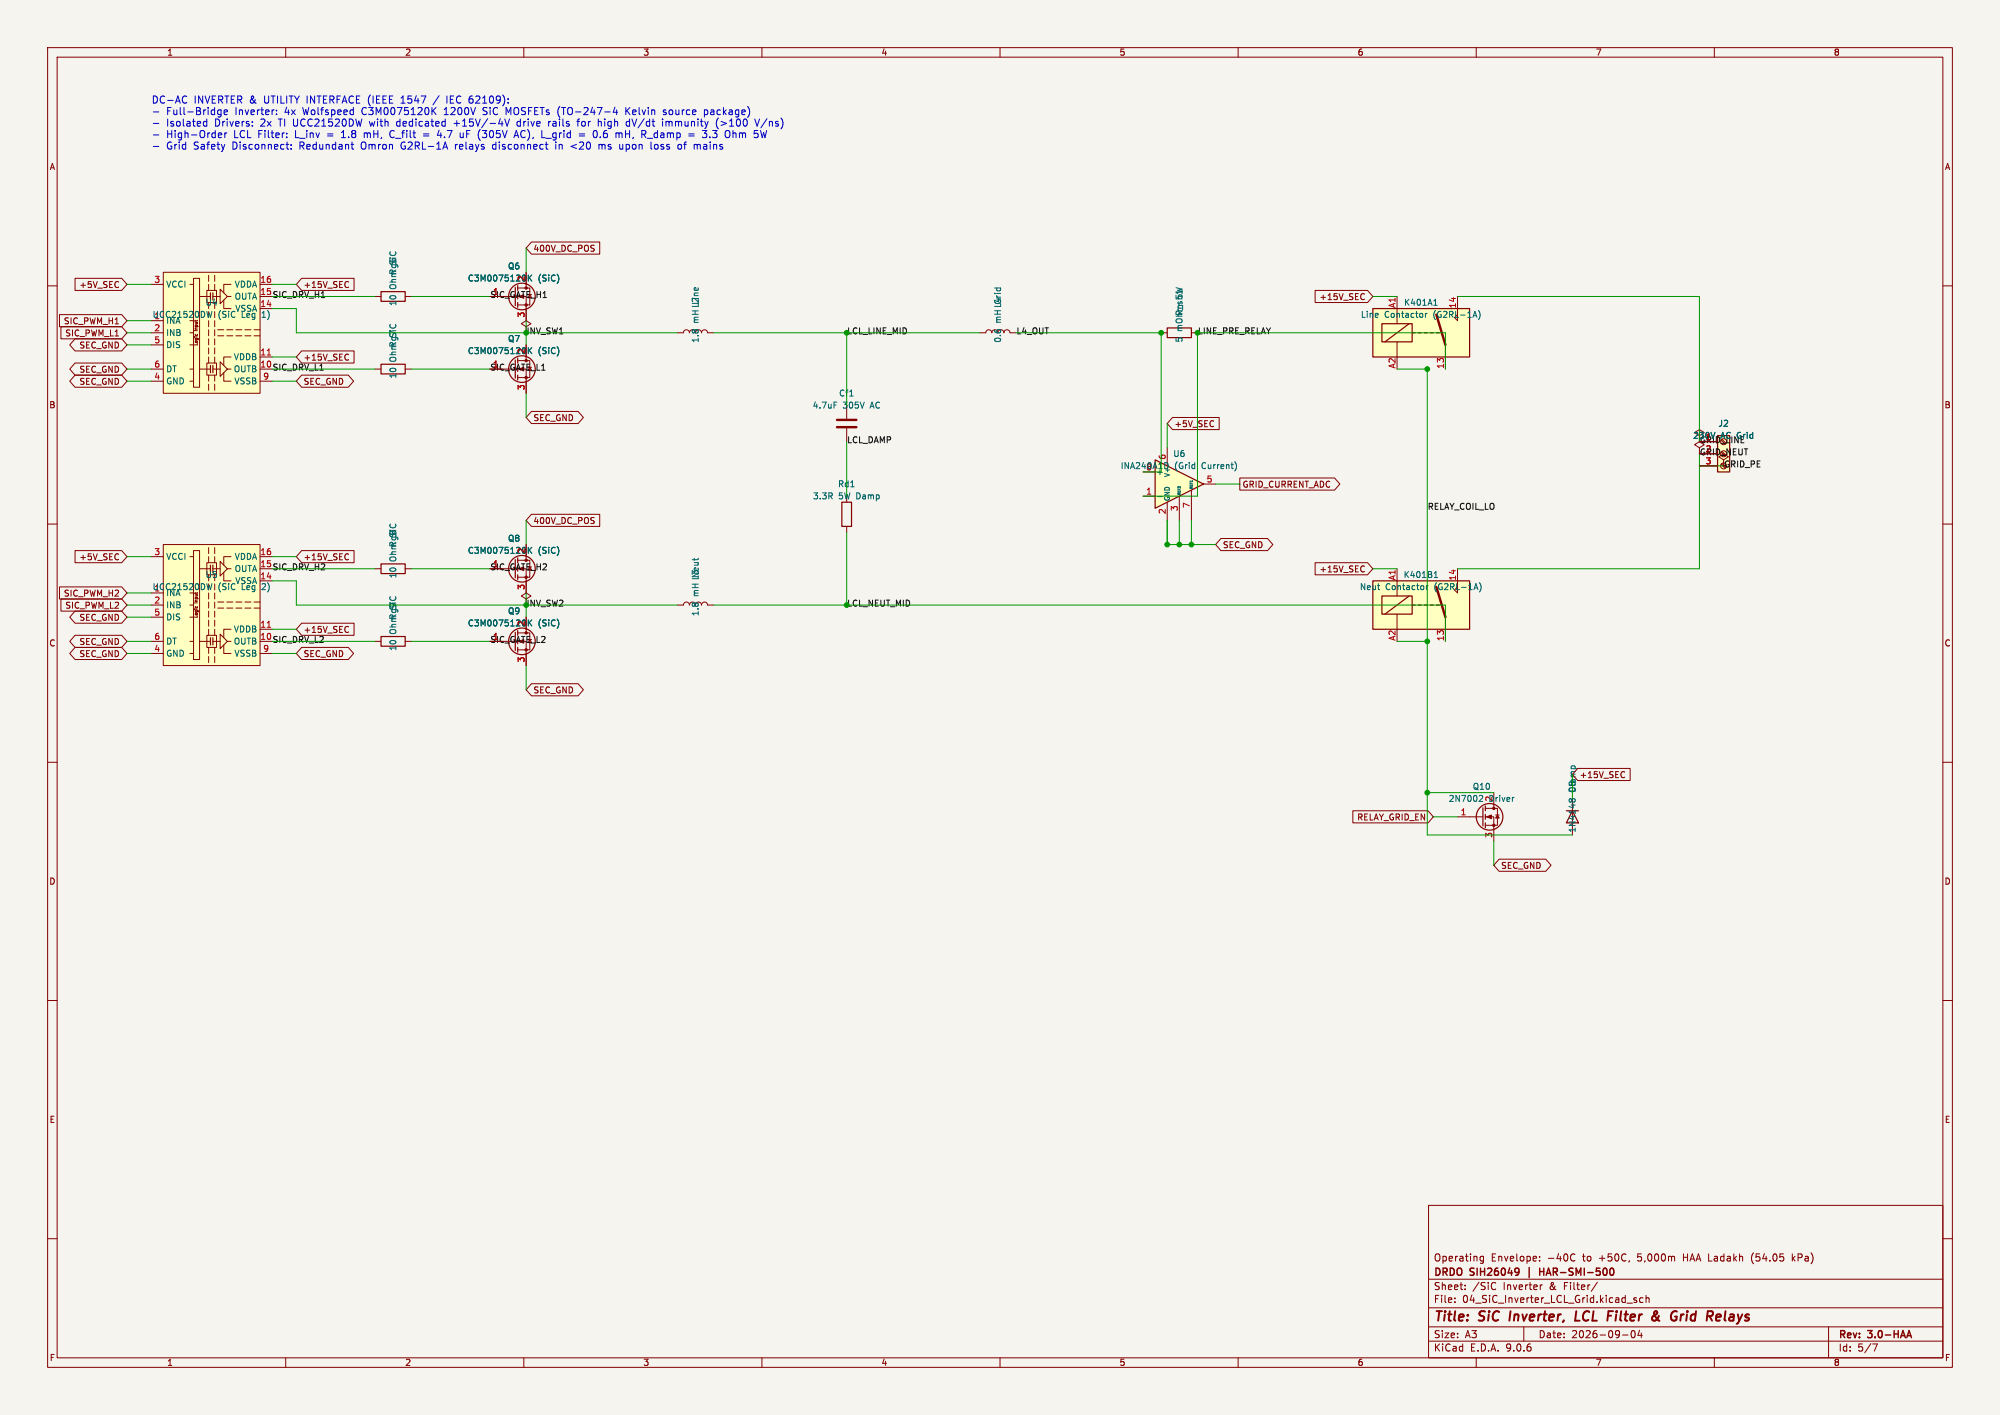
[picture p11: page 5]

INA240A1D (Grid Current) R_sh1 5 mOhm 5W Rg9 10 Ohm SiC Rg6 10 Ohm SiC

Id: 5/7 Title: SiC Inverter, LCL Filter & Grid Relays

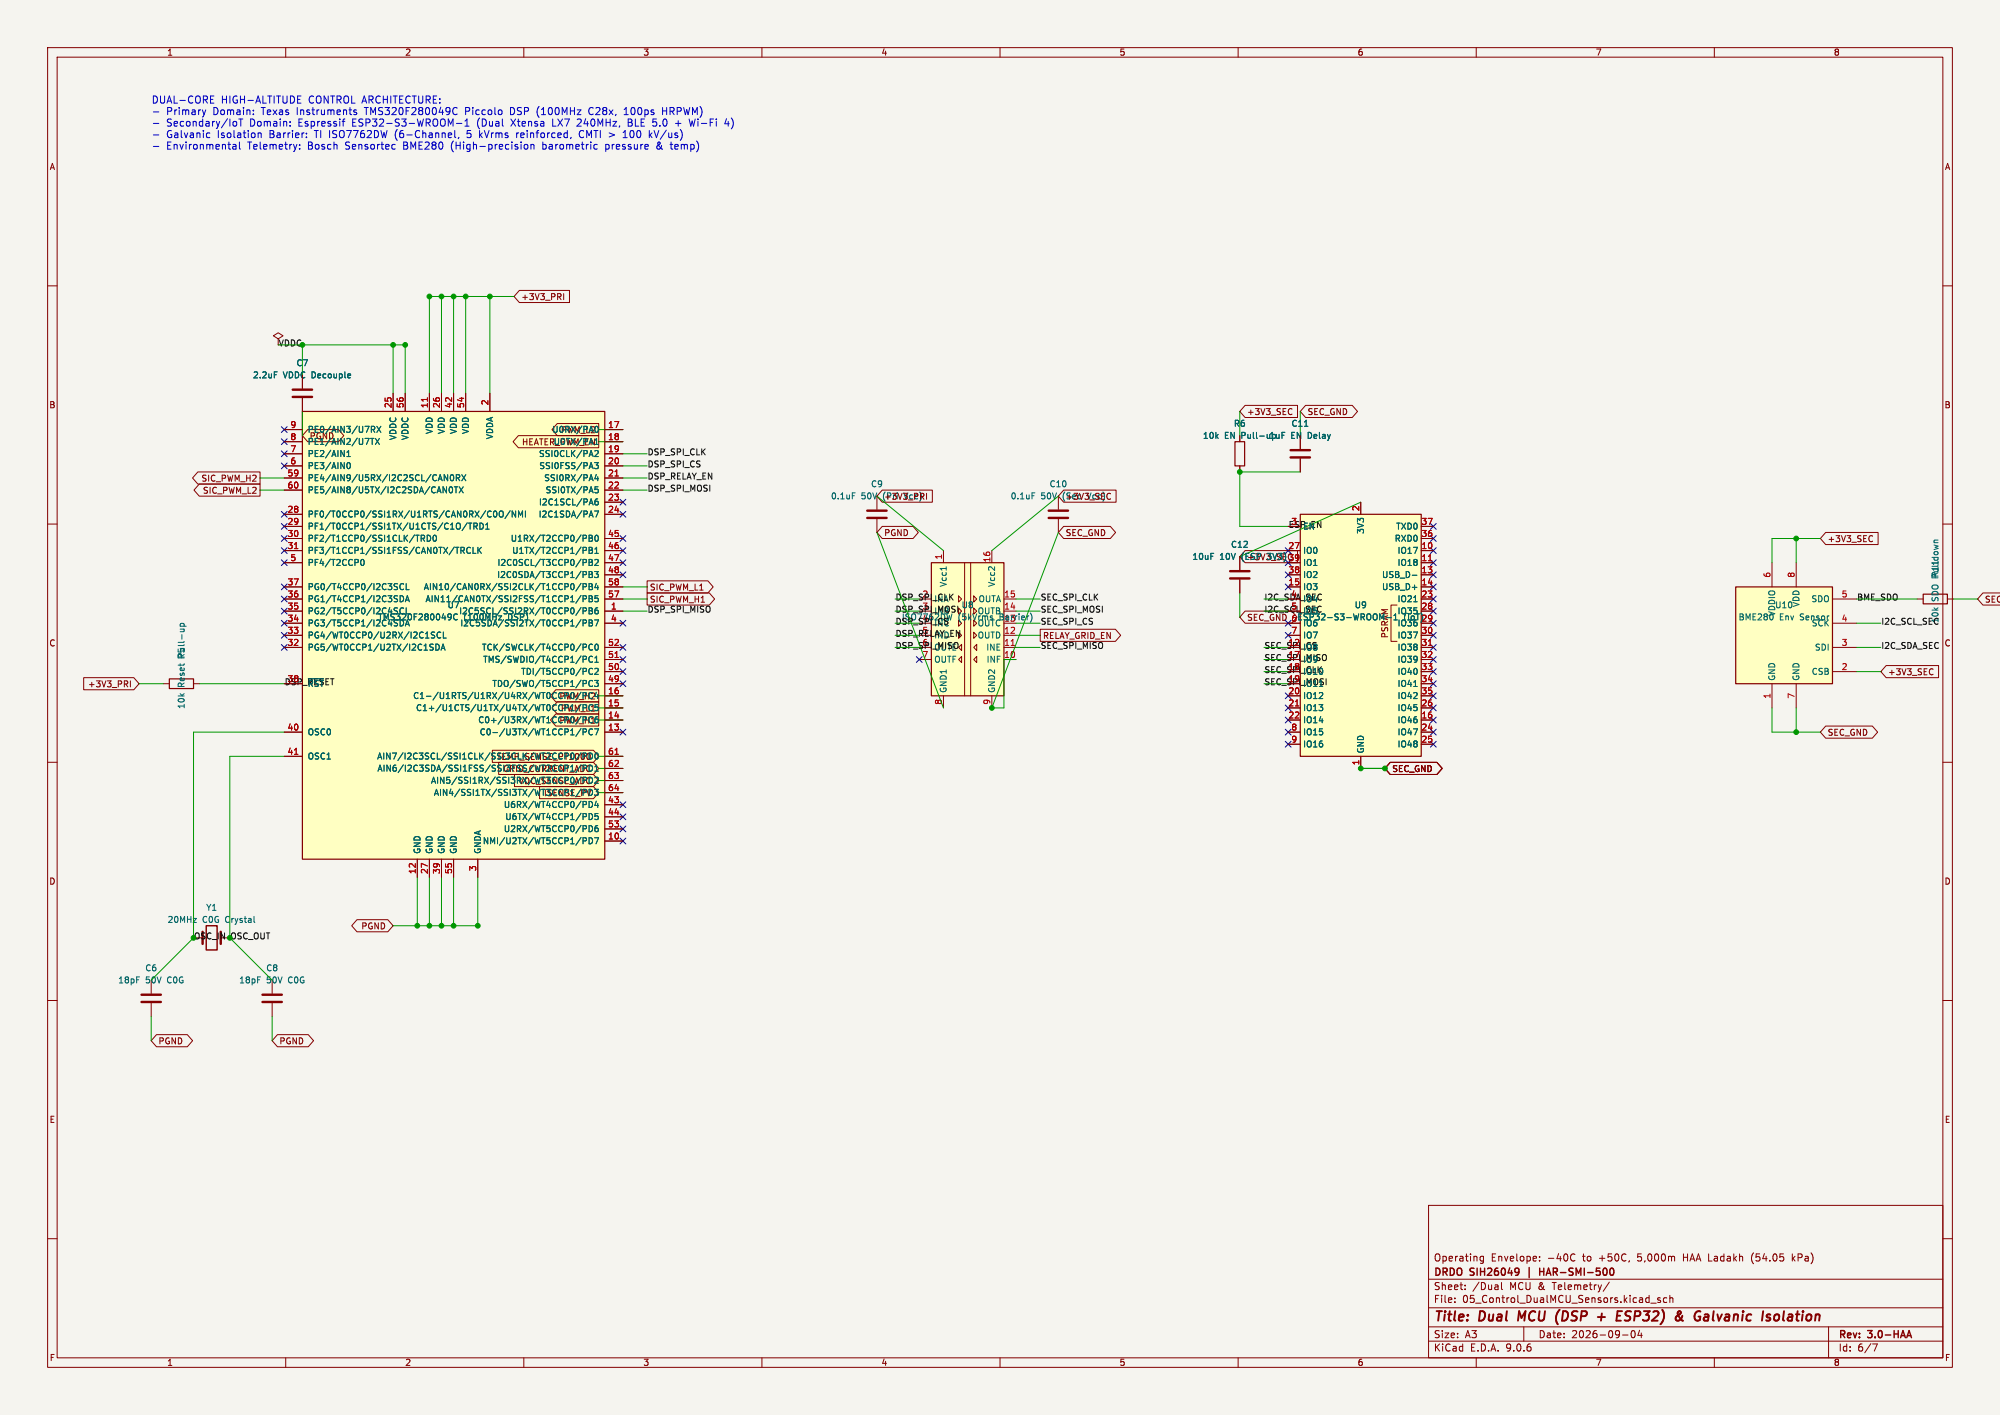
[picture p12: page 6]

9 OUTA 15 OUTB 14 OUTC 13 OUTD 12

Id: 6/7 Title: Dual MCU (DSP + ESP32) & Galvanic Isolation

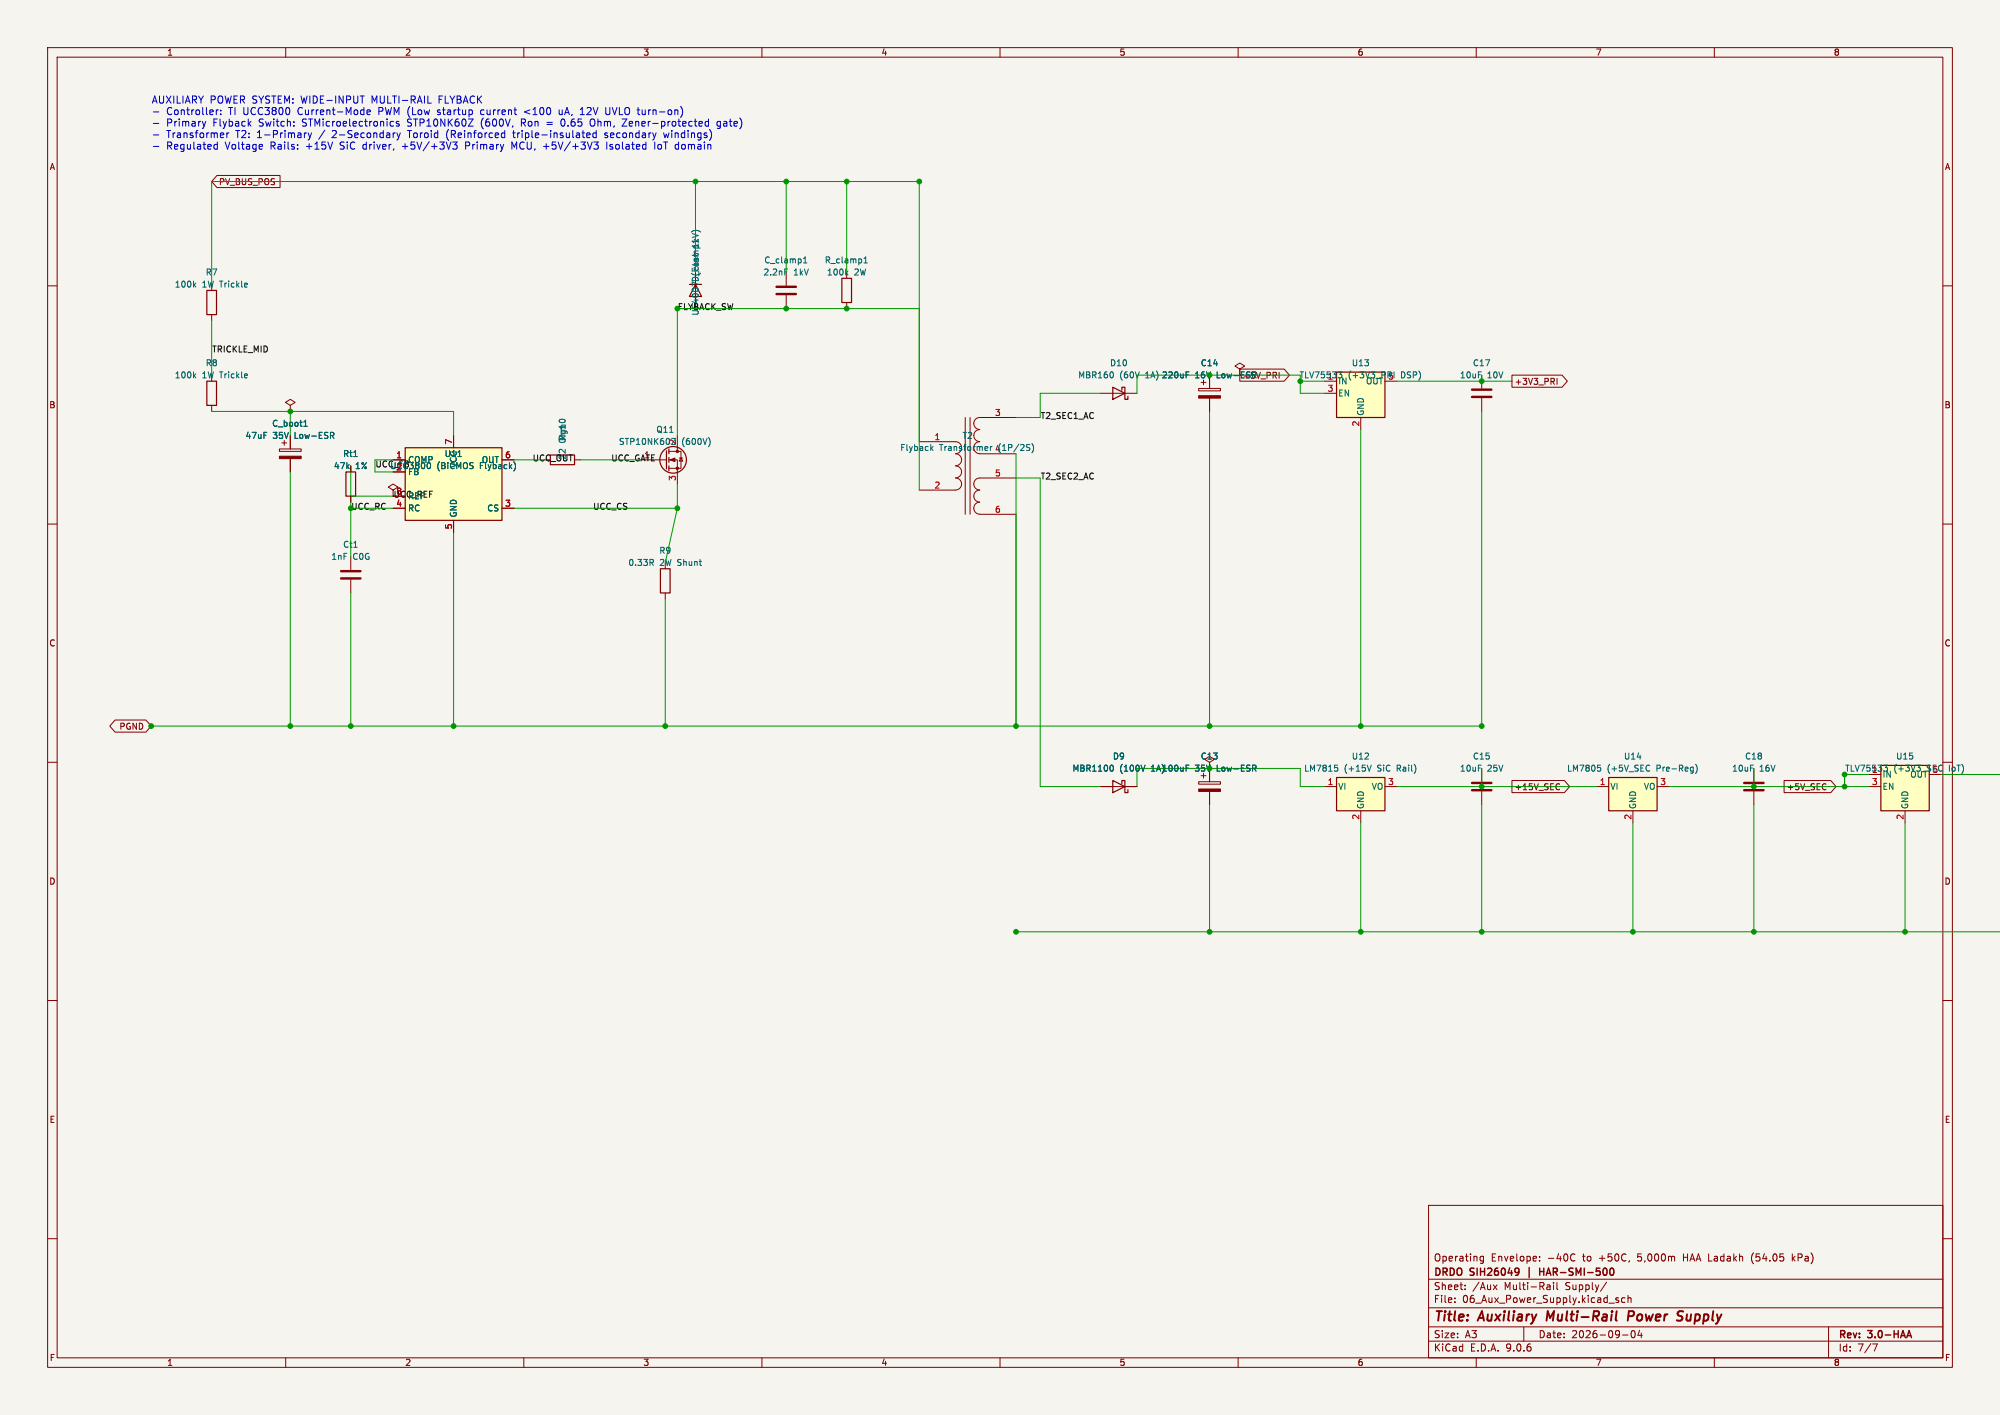
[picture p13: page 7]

UCC_FB AUXILIARY POWER SYSTEM: WIDE-INPUT MULTI-RAIL FLYBACK

5 OUT 6 CS 3 U11 UCC3800 (BiCMOS Flyback) 1

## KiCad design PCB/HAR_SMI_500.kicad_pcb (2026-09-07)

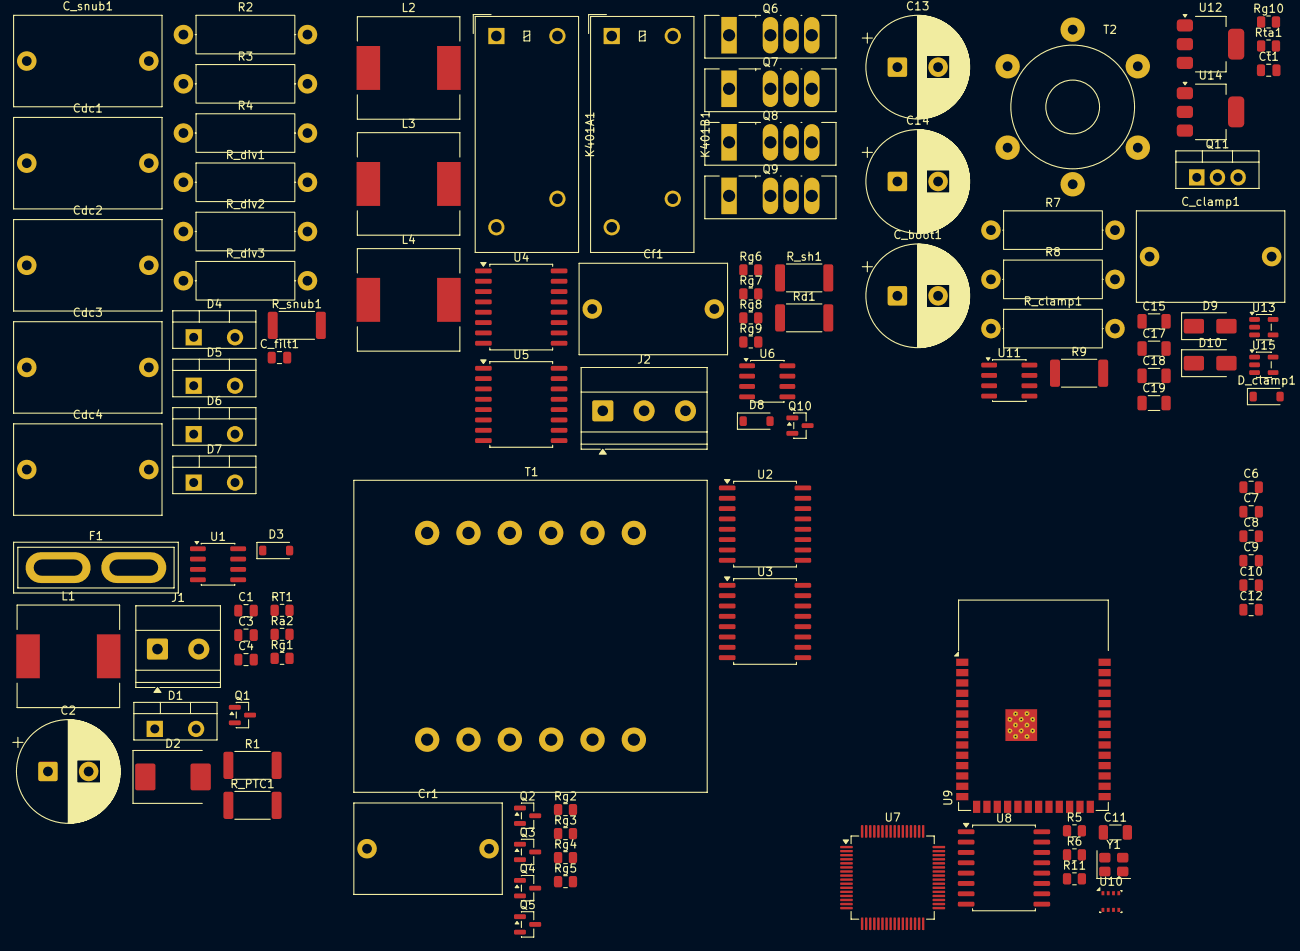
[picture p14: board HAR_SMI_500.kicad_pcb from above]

Board: 2 copper layers, 108 parts (0 on the bottom side), 90 nets, no tracks yet.

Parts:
C1: 10uF 100V X7R MLCC; C_0805_2012Metric
C2: 470uF 100V Electrolytic; CP_Radial_D12.5mm_P5.00mm
C3: 100nF 50V Decouple; C_0805_2012Metric
C4: 100nF 50V RTD Filter; C_0805_2012Metric
C6, C8: 18pF 50V C0G; C_0805_2012Metric
C7: 2.2uF VDDC Decouple; C_0805_2012Metric
C9: 0.1uF 50V (Pri Vcc); C_0805_2012Metric
C10: 0.1uF 50V (Sec Vcc); C_0805_2012Metric
C11: 1uF EN Delay; C_1206_3216Metric
C12: 10uF 10V (ESP 3V3); C_0805_2012Metric
C13: 100uF 35V Low-ESR; CP_Radial_D12.5mm_P5.00mm
C14: 220uF 16V Low-ESR; CP_Radial_D12.5mm_P5.00mm
C15: 10uF 25V; C_1206_3216Metric
C17, C19: 10uF 10V; C_1206_3216Metric
C18: 10uF 16V; C_1206_3216Metric
C_boot1: 47uF 35V Low-ESR; CP_Radial_D12.5mm_P5.00mm
C_clamp1: 2.2nF 1kV; C_Rect_L18.0mm_W11.0mm_P15.00mm_FKS3_FKP3
C_filt1: 10nF 50V C0G ADC Filter; C_0805_2012Metric
C_snub1: 1nF 1kV Ceramic; C_Rect_L18.0mm_W11.0mm_P15.00mm_FKS3_FKP3
Cdc1, Cdc2, Cdc3, Cdc4: 47uF 450V Polypropylene; C_Rect_L18.0mm_W11.0mm_P15.00mm_FKS3_FKP3
Cf1: 4.7uF 305V AC; C_Rect_L18.0mm_W11.0mm_P15.00mm_FKS3_FKP3
Cr1: 660nF 100V Resonant Cap; C_Rect_L18.0mm_W11.0mm_P15.00mm_FKS3_FKP3
Ct1: 1nF C0G; C_0805_2012Metric
D1: V30100P Schottky (30A, 100V); TO-220-2_Vertical
D2: 5.0SMDJ58A TVS (58V); D_SMC
D3, D8: 1N4148 Clamp; D_SOD-123
D4, D5, D6, D7: C3D10060A SiC (600V 10A); TO-220-2_Vertical
D9: MBR1100 (100V 1A); D_SMA
D10: MBR160 (60V 1A); D_SMA
D_clamp1: UF4007 (Fast 1kV); D_SOD-123
F1: 20A Fast Blade Fuse; Fuse_Blade_ATO_directSolder
J1: PV Input Terminal Block; TerminalBlock_Phoenix_MKDS-1,5-2-5.08_1x02_P5.08mm_Horizont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
J2: 230V AC Grid; TerminalBlock_Phoenix_MKDS-1,5-3-5.08_1x03_P5.08mm_Horizont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
K401A1: Line Contactor (G2RL-1A); Relay_SPST_Omron_G2RL-1A
K401B1: Neut Contactor (G2RL-1A); Relay_SPST_Omron_G2RL-1A
L1: 0.8mH CM Choke (20A); L_12x12mm_H8mm
L2: 1.8 mH Line; L_12x12mm_H8mm
L3: 1.8 mH Neut; L_12x12mm_H8mm
L4: 0.6 mH Grid; L_12x12mm_H8mm
Q1: CSD18540Q5B (60V 100A); SOT-23
Q2, Q3, Q4, Q5: EPC2020 (60V GaN); SOT-23
Q6, Q7, Q8, Q9: C3M0075120K (SiC); TO-247-4_Vertical
Q10: 2N7002 Driver; SOT-23
Q11: STP10NK60Z (600V); TO-220-3_Vertical
R1: 2 mOhm 5W 0.1% Shunt; R_2512_6332Metric
R2, R3, R4: 150k 1W HV Bleeder; R_Axial_DIN0414_L11.9mm_D4.5mm_P15.24mm_Horizontal
R5: 10k Reset Pull-up; R_0805_2012Metric
R6: 10k EN Pull-up; R_0805_2012Metric
R7, R8: 100k 1W Trickle; R_Axial_DIN0414_L11.9mm_D4.5mm_P15.24mm_Horizontal
R9: 0.33R 2W Shunt; R_2512_6332Metric
R11: 10k SDO Pulldown; R_0805_2012Metric
RT1: PT1000 RTD Sensor; R_0805_2012Metric
R_PTC1: 25W Ceramic PTC Heater; R_2512_6332Metric
R_clamp1: 100k 2W; R_Axial_DIN0414_L11.9mm_D4.5mm_P15.24mm_Horizontal
R_div1, R_div2: 499k 0.1% HV Divider; R_Axial_DIN0414_L11.9mm_D4.5mm_P15.24mm_Horizontal
R_div3: 10k 0.1% Low-Side; R_Axial_DIN0414_L11.9mm_D4.5mm_P15.24mm_Horizontal
R_sh1: 5 mOhm 5W; R_2512_6332Metric
R_snub1: 22 Ohm 2W Flameproof; R_2512_6332Metric
Ra2: 1.00k 0.1% RTD Bias; R_0805_2012Metric
Rd1: 3.3R 5W Damp; R_2512_6332Metric
Rg1: 10 Ohm Gate; R_0805_2012Metric
Rg2, Rg3, Rg4, Rg5: 4.7 Ohm GaN; R_0805_2012Metric
Rg6, Rg7, Rg8, Rg9: 10 Ohm SiC; R_0805_2012Metric
Rg10: 22 Ohm; R_0805_2012Metric
Rta1: 47k 1%; R_0805_2012Metric
T1: Planar Transformer 1:12; Transformer_37x44
T2: Flyback Transformer (1P/2S); Transformer_Toroid_Tapped_Horizontal_D14.0mm_Amidon-T50
U1: INA240A1D (Gain=20); SOIC-8_3.9x4.9mm_P1.27mm
U2: UCC21520DW (GaN Leg A); SOIC-16W_7.5x10.3mm_P1.27mm
U3: UCC21520DW (GaN Leg B); SOIC-16W_7.5x10.3mm_P1.27mm
U4: UCC21520DW (SiC Leg 1); SOIC-16W_7.5x10.3mm_P1.27mm
U5: UCC21520DW (SiC Leg 2); SOIC-16W_7.5x10.3mm_P1.27mm
U6: INA240A1D (Grid Current); SOIC-8_3.9x4.9mm_P1.27mm
U7: TMS320F280049C (100MHz DSP); LQFP-64_10x10mm_P0.5mm
U8: ISO7762DW (5kVrms Barrier); SOIC-16W_7.5x10.3mm_P1.27mm
U9: ESP32-S3-WROOM-1 (IoT); ESP32-S3-WROOM-1
U10: BME280 Env Sensor; Bosch_LGA-8_2.5x2.5mm_P0.65mm_ClockwisePinNumbering
U11: UCC3800 (BiCMOS Flyback); SOIC-8_3.9x4.9mm_P1.27mm
U12: LM7815 (+15V SiC Rail); SOT-223-3_TabPin2
U13: TLV75533 (+3V3_PRI DSP); SOT-23-5
U14: LM7805 (+5V_SEC Pre-Reg); SOT-223-3_TabPin2
U15: TLV75533 (+3V3_SEC IoT); SOT-23-5
Y1: 20MHz C0G Crystal; Crystal_SMD_3225-4Pin_3.2x2.5mm

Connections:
400V_DC_POS: Cdc1.1, Cdc2.1, Cdc3.1, Cdc4.1, D4.1 (K), D6.1 (K), Q6.2 (D), Q8.2 (D), R2.1, R3.1, R4.1, R_div1.1
+3V3_PRI: C9.1, C17.1, R5.1, Ra2.1, U7.2 (VDDA), U7.11 (VDD), U7.26 (VDD), U7.42 (VDD), U7.54 (VDD), U8.1 (Vcc1), U13.5 (OUT)
+3V3_SEC: C10.1, C12.1, C19.1, R6.1, U8.16 (Vcc2), U9.2 (3V3), U10.2 (CSB), U10.6 (VDDIO), U10.8 (VDD), U15.5 (OUT)
+5V_PRI: C1.2, C2.2, C3.1, C3.2, C4.2, C6.2, C7.2, C8.2, C9.2, C13.2, C14.1, C14.2, C15.2, C17.2, C18.2, C19.2, C_boot1.2, Ct1.2, D2.2 (A2), D10.1 (K), J1.2, Q1.3 (S), Q3.3 (S), Q5.3 (S), R9.2, RT1.2, T2.4 (SB), T2.6 (SD), U1.2 (GND), U1.3 (REF2), U1.4 (GND), U1.6 (V+), U1.7 (REF1), U2.3 (VCCI), U2.4 (GND), U2.5 (DIS), U2.6 (DT), U2.8 (VCCI), U2.9 (VSSB), U2.11 (VDDB), U2.16 (VDDA), U3.3 (VCCI), U3.4 (GND), U3.5 (DIS), U3.6 (DT), U3.8 (VCCI), U3.9 (VSSB), U3.11 (VDDB), U3.16 (VDDA), U7.3 (GNDA), U7.12 (GND), U7.27 (GND), U7.39 (GND), U7.55 (GND), U8.8 (GND1), U11.5 (GND), U12.2 (GND), U13.1 (IN), U13.2 (GND), U13.3 (EN), U14.2 (GND), U15.2 (GND)
+5V_SEC: C18.1, U4.3 (VCCI), U4.8 (VCCI), U5.3 (VCCI), U5.8 (VCCI), U6.6 (V+), U14.3 (VO), U15.1 (IN), U15.3 (EN)
+15V_SEC: C15.1, D8.1 (K), K401A1.A1, K401B1.A1, U4.11 (VDDB), U4.16 (VDDA), U5.11 (VDDB), U5.16 (VDDA), U12.3 (VO), U14.1 (VI)
/Aux Multi-Rail Supply/FLYBACK_SW: C_clamp1.2, D_clamp1.2 (A), Q11.2 (D), R_clamp1.2
/Aux Multi-Rail Supply/T2_SEC1_AC: D10.2 (A), T2.3 (SA)
/Aux Multi-Rail Supply/T2_SEC2_AC: D9.2 (A), T2.5 (SC)
/Aux Multi-Rail Supply/TRICKLE_MID: R7.2, R8.1
/Aux Multi-Rail Supply/UCC_CS: Q11.3 (S), R9.1, U11.3 (CS)
/Aux Multi-Rail Supply/UCC_FB: U11.1 (COMP), U11.2 (FB)
/Aux Multi-Rail Supply/UCC_GATE: Q11.1 (G), Rg10.2
/Aux Multi-Rail Supply/UCC_OUT: Rg10.1, U11.6 (OUT)
/Aux Multi-Rail Supply/UCC_RC: Ct1.1, Rta1.2, U11.4 (RC)
/Aux Multi-Rail Supply/UCC_REF: Rta1.1, U11.8 (REF)
/Dual MCU & Telemetry/BME_SDO: R11.1, U10.5 (SDO)
/Dual MCU & Telemetry/DSP_RELAY_EN: U7.21 (SSI0RX/PA4), U8.5 (IND)
/Dual MCU & Telemetry/DSP_RESET: R5.2, U7.38 (~RST)
/Dual MCU & Telemetry/DSP_SPI_CLK: U7.19 (SSI0CLK/PA2), U8.2 (INA)
/Dual MCU & Telemetry/DSP_SPI_CS: U7.20 (SSI0FSS/PA3), U8.4 (INC)
/Dual MCU & Telemetry/DSP_SPI_MISO: U7.1 (I2C5SCL/SSI2RX/T0CCP0/PB6), U8.6 (OUTE)
/Dual MCU & Telemetry/DSP_SPI_MOSI: U7.22 (SSI0TX/PA5), U8.3 (INB)
/Dual MCU & Telemetry/ESP_EN: C11.2, R6.2, U9.3 (EN)
/Dual MCU & Telemetry/I2C_SCL_SEC: U9.5 (IO5), U10.4 (SCK)
/Dual MCU & Telemetry/I2C_SDA_SEC: U9.4 (IO4), U10.3 (SDI)
/Dual MCU & Telemetry/OSC_IN: C6.1, U7.40 (OSC0), Y1.1
/Dual MCU & Telemetry/OSC_OUT: C8.1, U7.41 (OSC1), Y1.2
/Dual MCU & Telemetry/SEC_SPI_CLK: U8.15 (OUTA), U9.18 (IO10)
/Dual MCU & Telemetry/SEC_SPI_CS: U8.13 (OUTC), U9.12 (IO8)
/Dual MCU & Telemetry/SEC_SPI_MISO: U8.11 (INE), U9.17 (IO9)
/Dual MCU & Telemetry/SEC_SPI_MOSI: U8.14 (OUTB), U9.19 (IO11)
/Dual MCU & Telemetry/VDDC: C7.1, U7.25 (VDDC), U7.56 (VDDC)
/LLC Converter & GaN/LLC_DRV_H1: Rg4.1, U2.15 (OUTA)
/LLC Converter & GaN/LLC_DRV_H2: Rg2.1, U3.15 (OUTA)
/LLC Converter & GaN/LLC_DRV_L1: Rg5.1, U2.10 (OUTB)
/LLC Converter & GaN/LLC_DRV_L2: Rg3.1, U3.10 (OUTB)
/LLC Converter & GaN/LLC_GATE_H1: Q2.1 (G), Rg4.2
/LLC Converter & GaN/LLC_GATE_H2: Q4.1 (G), Rg2.2
/LLC Converter & GaN/LLC_GATE_L1: Q3.1 (G), Rg5.2
/LLC Converter & GaN/LLC_GATE_L2: Q5.1 (G), Rg3.2
/LLC Converter & GaN/LLC_MID_TANK: Cr1.2, T1.1 (AA)
/LLC Converter & GaN/SW_A: Cr1.1, Q2.3 (S), Q3.2 (D), U2.14 (VSSA)
/LLC Converter & GaN/SW_B: Q4.3 (S), Q5.2 (D), T1.2 (AB), U3.14 (VSSA)
/PV Input & Protection/HEATER_SW_DRAIN: D3.2 (A), Q1.2 (D), R_PTC1.2
/PV Input & Protection/PV_FILT_POS: C1.1, C2.1, L1.2, R1.1, U1.8 (+)
/PV Input & Protection/PV_IN_FUSE: D1.2 (A), F1.2
/PV Input & Protection/PV_IN_PROT: D1.1 (K), D2.1 (A1), L1.1
/PV Input & Protection/PV_IN_RAW: F1.1, J1.1
/SiC Inverter & Filter/GRID_LINE: J2.1, K401A1.14
/SiC Inverter & Filter/GRID_NEUT: J2.2, K401B1.14
/SiC Inverter & Filter/INV_SW1: L2.1, Q6.3 (S), Q7.2 (D), U4.14 (VSSA)
/SiC Inverter & Filter/INV_SW2: L3.1, Q8.3 (S), Q9.2 (D), U5.14 (VSSA)
/SiC Inverter & Filter/L4_OUT: L4.2, R_sh1.1, U6.8 (+)
/SiC Inverter & Filter/LCL_DAMP: Cf1.2, Rd1.1
/SiC Inverter & Filter/LCL_LINE_MID: Cf1.1, L2.2, L4.1
/SiC Inverter & Filter/LCL_NEUT_MID: K401B1.13, L3.2, Rd1.2
/SiC Inverter & Filter/LINE_PRE_RELAY: K401A1.13, R_sh1.2, U6.1 (-)
/SiC Inverter & Filter/RELAY_COIL_LO: D8.2 (A), K401A1.A2, K401B1.A2, Q10.2 (D)
/SiC Inverter & Filter/SIC_DRV_H1: Rg6.1, U4.15 (OUTA)
/SiC Inverter & Filter/SIC_DRV_H2: Rg8.1, U5.15 (OUTA)
/SiC Inverter & Filter/SIC_DRV_L1: Rg7.1, U4.10 (OUTB)
/SiC Inverter & Filter/SIC_DRV_L2: Rg9.1, U5.10 (OUTB)
/SiC Inverter & Filter/SIC_GATE_H1: Q6.1 (G), Rg6.2
/SiC Inverter & Filter/SIC_GATE_H2: Q8.1 (G), Rg8.2
/SiC Inverter & Filter/SIC_GATE_L1: Q7.1 (G), Rg7.2
/SiC Inverter & Filter/SIC_GATE_L2: Q9.1 (G), Rg9.2
GRID_CURRENT_ADC: U6.5, U7.62 (AIN6/I2C3SDA/SSI1FSS/SSI3FSS/WT2CCP1/PD1)
HEATER_PWM_EN: Rg1.1, U7.18 (U0TX/PA1)
ISENSE_PV: U1.5, U7.64 (AIN4/SSI1TX/SSI3TX/WT3CCP1/PD3)
unnamed: C_snub1.2, R_snub1.1
unnamed: C13.1, D9.1 (K), U12.1 (VI)
unnamed: Q1.1 (G), Rg1.2
unnamed: R_div1.2, R_div2.1
unnamed: C_boot1.1, R8.2, U11.7 (VCC)
PV_BUS_POS: C_clamp1.1, D3.1 (K), D_clamp1.1 (K), Q2.2 (D), Q4.2 (D), R1.2, R7.1, R_PTC1.1, R_clamp1.1, T2.1 (AA), T2.2 (AB), U1.1 (-)
PWM_H1: U2.1 (INA), U7.14 (C0+/U3RX/WT1CCP0/PC6)
PWM_H2: U3.1 (INA), U7.16 (C1-/U1RTS/U1RX/U4RX/WT0CCP0/PC4)
PWM_L1: U2.2 (INB), U7.15 (C1+/U1CTS/U1TX/U4TX/WT0CCP1/PC5)
PWM_L2: U3.2 (INB), U7.17 (U0RX/PA0)
RELAY_GRID_EN: Q10.1 (G), U8.12 (OUTD)
SEC_GND: C10.2, C11.1, C12.2, C_filt1.2, Cdc1.2, Cdc2.2, Cdc3.2, Cdc4.2, D5.2 (A), D7.2 (A), Q7.3 (S), Q9.3 (S), Q10.3 (S), R2.2, R3.2, R4.2, R11.2, R_div3.2, U4.4 (GND), U4.5 (DIS), U4.6 (DT), U4.9 (VSSB), U5.4 (GND), U5.5 (DIS), U5.6 (DT), U5.9 (VSSB), U6.2 (GND), U6.3 (REF2), U6.4 (GND), U6.7 (REF1), U8.9 (GND2), U8.10 (INF), U9.1 (GND), U9.40 (GND), U9.41 (GND), U10.1 (GND), U10.7 (GND)
SIC_PWM_H1: U4.1 (INA), U7.57 (AIN11/CAN0TX/SSI2FSS/T1CCP1/PB5)
SIC_PWM_H2: U5.1 (INA), U7.59 (PE4/AIN9/U5RX/I2C2SCL/CAN0RX)
SIC_PWM_L1: U4.2 (INB), U7.58 (AIN10/CAN0RX/SSI2CLK/T1CCP0/PB4)
SIC_PWM_L2: U5.2 (INB), U7.60 (PE5/AIN8/U5TX/I2C2SDA/CAN0TX)
T1_SEC_N: D6.2 (A), D7.1 (K), R_snub1.2, T1.3 (SA)
T1_SEC_P: C_snub1.1, D4.2 (A), D5.1 (K), T1.4 (SB)
TEMP_SENSE_PT1000: C4.1, RT1.1, Ra2.2, U7.61 (AIN7/I2C3SCL/SSI1CLK/SSI3CLK/WT2CCP0/PD0)
VDC_SENSE_ADC: C_filt1.1, R_div2.2, R_div3.1, U7.63 (AIN5/SSI1RX/SSI3RX/WT3CCP0/PD2)

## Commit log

2026-09-07 Add files via upload
    Add this file to .kicad_pcb (import session file) to create DRC free routing
2026-09-12 Add files via upload
    error fixed
    [03_Secondary_Rectifier_DCLink.kicad_sch]
